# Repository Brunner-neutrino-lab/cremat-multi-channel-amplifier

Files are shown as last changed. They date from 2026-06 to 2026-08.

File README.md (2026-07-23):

# Multi-channel Cremat amplifier

A **12-channel** SiPM charge-sensitive preamplifier + Gaussian shaper board, derived
from the Brunner-lab **6-channel Cremat CSP & Shaper board**
([`cremat-x6-board`](reference/cremat-x6-board/)) with four deliberate changes:

1. **12 channels** (was 6).
2. **0805 passives wherever possible** (was a mix of larger imperial sizes).
3. **A Cremat CR-210 baseline restorer on every channel**, *optional* — populate the
   module **or** an 0805 `0R` jumper to bypass it.
4. **An on-board SiPM bias front-end on every channel**: a `BIAS_IN` feed through an
   *optional* RC-in-series-with-R **bias filter**, then a node shared by the **SiPM**
   (DC-coupled) and the **amplifier** (AC-coupled). The detector and the amplifier hang
   off the same biased node.

> This repository is the **design specification + build documentation** for the new
> board. It is structured to mirror the Brunner-lab **`ets-breakout`** project, which is
> included as the *reference for how to document and build*. The KiCad implementation is
> the next track (see [Status](#status)).

## What each channel does (new signal chain)

```
                          bias filter (optional, 0R-bypassable)
 BIAS_IN ───►  Rf1 ──┬── Rf2 ──►──┐
                     │            │   FRONT-END NODE
                    Cf            ├─────────────► SIPM   (DC-coupled: reverse-biases the detector)
                     │            │
                    GND           └─► Cc ─► CR-11X ─► CR-200-X ─► [CR-210] ─► buffer ─► OUTPUT
                                     (AC)   CSP        shaper     BLR(opt)   THS3491    (50 Ω
                                                       +P/Z trim  0R-byp.    DNP-def     coax)
```

- **`BIAS_IN` → bias filter → front-end node.** "RC in series with R": series `Rf1`,
  shunt `Cf` to ground, series `Rf2`. The whole filter is bypassable with 0R jumpers.
- **Front-end node → `SIPM` (DC-coupled).** The filtered bias voltage reverse-biases the
  detector directly.
- **Front-end node → `Cc` → amplifier (AC-coupled).** Only the SiPM's fast current pulse
  reaches the charge-sensitive preamp; the DC bias is blocked by `Cc`.
- **CR-11X → CR-200-X → CR-210 → buffer → output**, the classic Cremat chain. The CR-210
  baseline restorer is new and optional.

Full detail: [docs/hardware/channel.md](docs/hardware/channel.md).

## Documentation map

> **Looking for the actual orderable board? It is [`final-board/twelve-channel/`](final-board/twelve-channel/).**
> Reviewing it → [REVIEW.md](final-board/twelve-channel/REVIEW.md) · ordering it →
> [ORDERING.md](final-board/twelve-channel/ORDERING.md) · resuming work on it →
> [HANDOFF.md](final-board/twelve-channel/HANDOFF.md).

| Doc | Contents |
|-----|---|
| **[final-board/twelve-channel/REVIEW.md](final-board/twelve-channel/REVIEW.md)** | **Design-review pack** — verified state, the acceptance gate, and what needs human eyes before ordering |
| [final-board/twelve-channel/INTERFACE.md](final-board/twelve-channel/INTERFACE.md) | The final board: layout intent, connector map, stackup, per-channel cell |
| [final-board/twelve-channel/ORDERING.md](final-board/twelve-channel/ORDERING.md) | Buy sheet — JLCPCB (fab + SMT) + DigiKey (hand parts), quantities, upload steps |
| [final-board/twelve-channel/HANDOFF.md](final-board/twelve-channel/HANDOFF.md) | Resume on a new machine: toolchain, paths, regeneration commands, gotchas |
| [docs/agent-project/](docs/agent-project/) | **Parallel agent-developed build** — bottom-up (per-chip eval boards → single channel → 12-ch board), 12 tracks with briefs, conventions, session-log/report protocol. **Start at [docs/agent-project/README.md](docs/agent-project/README.md).** *(Historical: intermediate figures here — e.g. bias ≤ 60 V, board 235.1 × 264.1 mm — are superseded by the final board.)* |
| [docs/development-plan.md](docs/development-plan.md) | Earlier work-track breakdown (the rapid top-down build in `hardware/`); superseded by the agent-project for the final design |
| [docs/architecture.md](docs/architecture.md) | System/board block diagram, channel signal chain, design partitioning |
| [docs/modifications.md](docs/modifications.md) | **The four changes vs. `cremat-x6-board`, with rationale + the optional/DNP jumper scheme** |
| [docs/hardware/channel.md](docs/hardware/channel.md) | Per-channel circuit: bias front-end, AC/DC coupling, CSP/shaper/BLR/buffer, jumpers |
| [docs/hardware/circuit-design.md](docs/hardware/circuit-design.md) | **Front-end values for the Hamamatsu VUV4** — bias filter, coupling, polarity, CR-112 gain/range |
| [docs/hardware/board.md](docs/hardware/board.md) | 12-channel board: power distribution, connectors, layout intent |
| [docs/hardware/bom.md](docs/hardware/bom.md) | 0805 strategy, Cremat modules, optional-population (DNP) variants |
| [docs/hardware/pcb-design-rules.md](docs/hardware/pcb-design-rules.md) | Net classes, trace widths, HV creepage, guard rings |
| [docs/hardware/component-libraries.md](docs/hardware/component-libraries.md) | Symbols + footprints to provide (Cremat SIP-8, 0805 passives, jumpers) |
| [docs/fabrication/fabrication-guide.md](docs/fabrication/fabrication-guide.md) | Fab output generation, assembly, population variants |
| [docs/operation/user-guide.md](docs/operation/user-guide.md) | Power-up, biasing SiPMs, choosing populate/bypass options |
| [docs/session-report.md](docs/session-report.md) | Integration/manager handoff: tracks, decisions, what's done vs. open |

## References (git submodules)

| Path | Repo | Role |
|---|---|---|
| [reference/cremat-x6-board/](reference/cremat-x6-board/) | `Brunner-neutrino-lab/cremat-x6-board` | **What we're building** — the 6-channel CR-110/CR-200 eval board this design derives from |
| [reference/ets-breakout/](reference/ets-breakout/) | `Brunner-neutrino-lab/ets-breakout` | **How we build/document** — KiCad-from-source-of-truth pipeline + doc structure to imitate |
| [reference/cremat-CR-160-R7/](reference/cremat-CR-160-R7/) | `CrematInc/CR-160-R7` | **CR-210 pinout + integration** — Cremat's open-source CR-200/CR-210 eval board (the CR-210 bypass-jumper scheme) |
| [reference/cremat-CR-150-R5/](reference/cremat-CR-150-R5/) | `CrematInc/CR-150-R5` | **CR-11X reference** — Cremat's open-source CSP eval board (source of the CR-11X symbol) |

Clone with submodules:

```
git clone --recurse-submodules <this-repo>
# or, in an existing clone:
git submodule update --init --recursive
```

## Status

- **Specification + documentation: complete.** This repo fully specifies the modified
  12-channel board.
- **Development is divided into tracks** — see [docs/development-plan.md](docs/development-plan.md).
  **Phase 1 is built:** [hardware/](hardware/) has the `kicad-cli`-validated symbol library
  ([hardware/lib/cremat.kicad_sym](hardware/lib/cremat.kicad_sym)), the project + net classes,
  lib tables, the fielded BOM ([hardware/bom/](hardware/bom/)), the golden per-channel netlist
  ([hardware/integration-notes.md](hardware/integration-notes.md)), and the mechanical spec
  ([hardware/mechanical.md](hardware/mechanical.md)). **Track 5 (schematic) is done** — the
  12-channel hierarchical schematic is generated by [hardware/gen_sch.py](hardware/gen_sch.py)
  and is **ERC-clean (0 errors)** with a netlist that matches the spec node-by-node. **Layout
  + fab (Tracks 6–7)** remain — guide: [hardware/BUILD-IN-KICAD.md](hardware/BUILD-IN-KICAD.md).
- **CR-210 pinout + bypass-jumper integration: confirmed** against Cremat's open-source
  [CR-160-R7](reference/cremat-CR-160-R7/) board (pin 2 = GND vs the CR-200's P/Z).
- **Build decisions resolved** (D1–D6, see the plan): bias ≤ 70 V (100 V parts); all
  per-channel I/O is **MCX `CONMCX013`** (`BIAS_IN`, `SIPM`, `TEST`, `OUT_50` — **`BIAS_IN` is
  per-channel**, 4/channel → 48 MCX/board); modules **CR-112** + **CR-200-1µs** (+ CR-210),
  **socketed** on Samtec SS-108-TT-2 SIP-8 sockets (36/board), the modules plug in; rack-mounted,
  **one board per 1U Hammond RM1U1908VBK case, boards daisy-chained**; first build = Full.
- **Front-end designed for the Hamamatsu VUV4** (S13370, 45–55 V, ≈220 fC/V, Cdet≈1.28 nF):
  bias filter `Rf1=Rf2=10 kΩ`, `Cf=100 nF`, `Cc=0.22 µF`; cathode-on-node +45–55 V; CR-112
  ([docs/hardware/circuit-design.md](docs/hardware/circuit-design.md)).
- **Enclosure (D5):** **Hammond RM1U1908VBK** (1U, vented), **one board per case**; boards are
  **daisy-chained** (each board in its own 1U box, `J_DAISY` passes the raw rails box-to-box).
  Board outline **213.2 × 334.7 mm**; it mounts on standoffs off the bottom cover and passes
  **through a ~340 × 7 mm milled slot** in each front/rear panel (slot-through, protruding ~5 mm;
  the MCX faces sit ~8.6 mm proud). Usable interior height 40.09 mm; tall parts must clear it.
  Inputs (`BIAS_IN`+`SIPM`) on one long edge, outputs (`OUT_50`) on the other (24 MCX per long edge).
- **Open items**: final jack/outline placement (Track 4), and bench-verify (CR-112 output
  sign, warm/cold OV offset, single-p.e. range, P/Z trim). Power terminals are resolved —
  two 3-pos 5.08 mm Phoenix screw terminals, `J_PWR` (supply in) + `J_DAISY` (raw rails out).

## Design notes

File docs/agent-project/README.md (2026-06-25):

# Agent-developed build — start here

This directory orchestrates the **parallel, agent-developed** rebuild of the amplifier
(bottom-up: per-chip eval boards → single channel → 12-channel board). Run sessions in
danger/bypass mode.

## Read order
1. [00-CHARTER.md](00-CHARTER.md) — phases, the 12 tracks, dependency graph, gating, locked decisions.
2. [01-CONVENTIONS.md](01-CONVENTIONS.md) — directory layout, log/report protocol, interface contracts, toolchain, **SPICE rules (use Cremat's official models)**, real-parts gate, sourcing rules, success-criteria philosophy.
3. Your **brief** (below). 4. The reports/`INTERFACE.md` your brief says to consume.

## How to assign a session
Give the new session this (fill in the track):

> You are **track `<ID>`** of the agent-developed Cremat amplifier project. Read
> `docs/agent-project/00-CHARTER.md`, `docs/agent-project/01-CONVENTIONS.md`, and your brief
> `docs/agent-project/briefs/<brief>.md`. Work only in your track subdir, keep
> `SESSION_LOG.md` (ground truth) + `SESSION_REPORT.md` (summary) current from the templates,
> update your row in `docs/agent-project/02-TRACKS.md`, define your success/failure criteria
> first, then execute autonomously. Honor the gates in the charter.

| Track | Brief | Subdir |
|---|---|---|
| A1 csp-design / A2 csp-sim / A3 csp-bom | [briefs/A-csp-cr112.md](briefs/A-csp-cr112.md) | `chips-board/csp-cr112/{design,sim,models-bom}/` |
| A4/A5/A6 shaper {design,sim,bom} | [briefs/A-shaper-cr200-cr210.md](briefs/A-shaper-cr200-cr210.md) | `chips-board/shaper-cr200-cr210/...` |
| B1/B2/B3 single-channel {design,sim,bom} | [briefs/B-single-channel.md](briefs/B-single-channel.md) | `integration/single-channel/...` |
| C1/C2/C3 twelve-channel {design,bom,sim} | [briefs/C-twelve-channel.md](briefs/C-twelve-channel.md) | `final-board/twelve-channel/...` |

Phase A (6 tracks) can all start now. Phase B gates on both Phase-A sub-components COMPLETE;
Phase C gates on single-channel COMPLETE. The **Coordinator** owns
[02-TRACKS.md](02-TRACKS.md) and marks COMPLETE.

## Prior art (read-only)
`reference/` (incl. Cremat's `cremat-CR-150-R5`, `cremat-CR-160-R7` eval boards), and the
earlier rapid build in `hardware/` + `docs/` — reuse the toolchain/scripts, but this
bottom-up build is the source of truth for the final design.

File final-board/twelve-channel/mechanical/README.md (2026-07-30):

# Box mounting — two boards stacked in a 2U rack case

Two 12-channel boards stacked on standoffs in **one Hammond RM2U1908VBK** 2U vented case
(DigiKey HM1166-ND). The other 3 assembled boards are spares (unboxed). Drawings are the
`*.svg` files here (regenerate with `python gen_drawings.py <png_out_dir>`).

## Box + board

| | mm |
|---|---|
| Box interior (Hammond drawing) | **84.53 H × 415.30 W × 196.85 D** |
| Board | 213.3 (depth, connectors) × 334.8 (width) × 1.6 |
| Board mounting holes | 4× M3 (3.2 mm) at board-x {8.0, 205.2}, board-y {5.0, 329.7} |

## Horizontal placement (drawings 1, 5)

- **Width:** board 334.8 mm centered → **40.25 mm clear each side.**
- **Depth:** board is 16.45 mm **deeper** than the box → protrudes **8.2 mm past each panel**;
  the 24+24 MCX sit proud through the front/rear slots.
- **Standoff holes (bottom cover):** X = **45.25 / 369.95** mm (from the left interior wall),
  Y ≈ **0 / 196.85** mm. ⚠ The hole rectangle (197.2 mm) is 0.35 mm wider than the 196.85 mm
  interior, so the holes land **right on the front/rear panel lines** — the front/rear panels
  need a small corner-relief cutout at X = 45.25 / 369.95 for the standoff columns (they're
  outside the connector-slot span X ≈ 69–356, so the relief is clean).

## Vertical stack (drawings 2, 3, 4) — target 1″ board-to-board

| From → to | height |
|---|---|
| bottom cover → board 1 | **12.7 mm (½″)** standoff |
| board 1 → board 2 | **25.4 mm (1″)** standoff — the board-to-board spec |
| board 2 → top cover | **43.2 mm** air |

Board planes (connector-slot centers): **Z = 13.5 mm** (board 1), **Z = 40.5 mm** (board 2).
Sum: 12.7 + 1.6 + 25.4 + 1.6 + 43.2 = 84.53 ✓.

A standing Cremat module is **~26.5 mm** (socket 4.2 + body ~22.3) — **1.1 mm taller than the
25.4 mm gap**, so **board 1's modules bend** to fit the inter-board gap (as on Cremat's own eval
boards); board 2's modules stand freely in the 43 mm top clearance.

*Standoff note:* the recommended in-stock parts are metric (12 mm / 25 mm), 0.7 / 0.4 mm short of
½″ / 1″. That makes board-to-board 25.0 mm (~0.98″); the 0.4 mm is absorbed by the top air. Source
true 25.4 / 12.7 mm M3 M-F standoffs if exact-inch is required.

## Panels (drawings 3, 4) — machine into the removable front/rear plates

- **2 connector slots** each, ~8 mm tall, X 69.2 → 356.2, at Z = 13.5 (board 1) and Z = 40.5 (board 2).
- **2 standoff-relief cutouts** each, ~8 mm wide, at X = 45.25 / 369.95, from the bottom up to Z ≈ 42.

## Standoff hardware (per box, DigiKey — see `../models-bom/digikey-hand-bom.csv`)

All M3. Both standoffs are **male-female, male-up** (an F-F bottom standoff won't mate with B).

| Role | MPN | DK PN | length |
|---|---|---|---|
| A — bottom cover → board 1 | Würth 971120321 | 732-10406-ND | 12 mm + 6 mm stud |
| B — board 1 → board 2 | Würth 971250321 | 732-971250321-ND | 25 mm + 6 mm stud |
| screw (into A, from under cover) | Keystone 29311 | 36-29311-ND | M3×6 mm pan |
| nut (top of B, fixes board 2) | Keystone 4708 | 36-4708-ND | M3 |

## Assembly (per the described order of operations)

1. Remove front, rear, and top panels. Machine the front/rear panel slots + corner reliefs.
2. Drill the 4 standoff holes in the bottom cover (match the PCB: X 45.25/369.95, Y ~0/196.85).
3. Screw the 4× standoff **A** (12 mm) to the bottom cover from below.
4. Slide **board 1** in through the front; drop onto standoffs A (male studs through the holes).
5. Thread the 4× standoff **B** (25 mm) onto A through board 1 → clamps board 1.
6. Slide **board 2** in; drop onto standoffs B; **fix a nut** on each top stud.
7. Refit the front/rear panels (over the protruding board edges / connectors) and the top.

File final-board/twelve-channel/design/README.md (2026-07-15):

# twelve-channel — design (schematic + PCB)

12-channel SiPM CSP + shaper + BLR + buffer board, built from the reworked single channel
(`../../../integration/single-channel/design/`) as the single source of truth.

- **Schematic** = KiCad **hierarchical**: the single channel (minus board power entry)
  instantiated 12× as `channel.kicad_sch`, plus a root `twelve-channel.kicad_sch` with the 12
  sheet instances + one common power section (power in + board-to-board daisy + up-rated
  reverse-polarity/PTC block + 470 µF bulk). Per-channel nets auto-scope to `/chNN/<net>`.
- **PCB** = **tile-and-replicate**: the routed single-channel channel row is cloned 12× (offset
  25 mm in Y, refs re-mapped via role, nets re-mapped `/X`→`/chNN/X`); board-wide plane pours
  carry the rails so the router does no per-channel work; only the common section is routed.

## Pipeline (run in order; KiCad 10 bundled Python)

```
PY="C:/Program Files/KiCad/10.0/bin/python.exe"
CLI="C:/Program Files/KiCad/10.0/bin/kicad-cli.exe"

# --- schematic ---
"$PY" gen_sch.py                       # -> channel.kicad_sch, twelve-channel.kicad_sch, .kicad_pro
"$CLI" sch erc twelve-channel.kicad_sch
"$CLI" sch export netlist --format kicadsexpr -o twelve-channel.net twelve-channel.kicad_sch

# --- PCB (needs twelve-channel.net from the step above) ---
"$PY" gen_pcb.py                       # tile x12 + common section + planes + outline (+ .kicad_dru)
"$PY" fill_zones.py                    # fill the 4 plane zones (separate pass; in-memory fill segfaults)
"$PY" polish_silk.py                   # move dense refdes/fields F.Silkscreen -> F.Fab
"$CLI" pcb drc --schematic-parity twelve-channel.kicad_pcb    # gate: 0 / 0 / 0
```

Note: `gen_pcb.py` resets silk and adds visible common-part fields, so **`polish_silk.py` must
run after every `gen_pcb.py`**. The `twelve-channel.net` netlist is the authoritative source
for the PCB's per-pad nets, footprint values, and BOM fields (regenerate it after any schematic
change before re-running `gen_pcb.py`).

## Result

213.2 × 334.7 mm, 4-layer (widened 138 → 180 → 213.2 mm to span the Hammond RM1U1908VBK 1U case —
one board per case, slot-through the front/rear panels; the output/bias MCX row was shifted to the
far edge with F.Cu trace extensions). 468 footprints (464 refdes'd parts + 4 M3), 4 plane
zones. (The BOM lists 500 line-item parts = the 464 placed + the 36 SIP-8 sockets, which
share the module sites' PinSocket_1x08 footprints.)
**DRC 0 violations / 0 unconnected / 0 schematic-parity.** Render: `twelve-channel-3d.png`.

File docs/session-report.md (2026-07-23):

# Session report — Multi-channel Cremat amplifier (integration track)

> **Superseded 2026-07-11 (historical setup-phase handoff).** The board is now BUILT and
> order-ready: 213.2 × 334.7 mm, 4-layer, one per Hammond RM1U1908VBK 1U case (slot-through,
> daisy-chained), THS3491 output buffer (DNP-by-default), socketed Cremat modules (Samtec
> SS-108-TT-2). The mechanical/part figures below (e.g. 225 × 235 mm, two boards side-by-side,
> EL5167) reflect the initial plan, not the final board. Current truth: `final-board/twelve-channel/`
> (INTERFACE.md, HANDOFF.md, ORDERING.md, SESSION_LOG sessions 12–15).

Handoff from the **organizing / integrating / managing** track. This session set up the
repository, integrated the two reference projects as submodules, and authored the full
design-specification documentation set for the modified 12-channel board. It did **not**
implement the KiCad project — that is the hardware track's job, and this report is its
brief.

---

## 1. What this session produced

- **Four git submodules under `reference/`:**
  - `cremat-x6-board` (`Brunner-neutrino-lab/cremat-x6-board`) — *what we build*: the
    6-channel CR-110/CR-200 eval board this design derives from.
  - `ets-breakout` (`Brunner-neutrino-lab/ets-breakout`) — *how we build/document*: the
    single-source-of-truth KiCad pipeline + the docs structure imitated here.
  - `cremat-CR-160-R7` (`CrematInc/CR-160-R7`) — *CR-210 reference*: Cremat's open-source
    CR-200/CR-210 eval board; the authority for the CR-210 pinout + bypass-jumper scheme.
  - `cremat-CR-150-R5` (`CrematInc/CR-150-R5`) — *CR-11X reference*: Cremat's open-source
    CSP eval board (origin of the CR-11X symbol).
- **A track breakdown** ([development-plan.md](development-plan.md)): one foundation track
  for parts/models/BOM, parallel tracks for circuit / integration / mechanical, then serial
  schematic → layout → fab tracks, with a dependency graph and the decision list.
- **A complete documentation set** (`README.md`, `CLAUDE.md`, `docs/…`) specifying the
  modified board, with the change list, per-channel circuit, board plan, BOM/DNP logic,
  PCB rules, library plan, fabrication, and operation.
- **Repo hygiene:** `.gitignore` for KiCad/Python/fab cruft.

The documentation is structured so a hardware track (or a future Claude session) can
implement the KiCad project directly from `docs/modifications.md` + the reference channel
sheet.

---

## 2. The design in one paragraph

Take the reference per-channel chain
(`coax → Cc → CR-113 → CR-200-X → buffer → 49.9R → coax`), and: (1) replicate it **12×**;
(2) move all passives to **0805**; (3) insert an **optional CR-210** baseline restorer
between shaper and buffer (0R-bypassable); (4) add an **on-board SiPM bias front-end** —
`BIAS_IN` through an optional RC-in-series-with-R filter to a node that feeds the **SiPM
DC-coupled** and the **amplifier AC-coupled** (via `Cc`). Both detector and amplifier hang
off the one biased node. Full detail in [modifications.md](modifications.md) and
[hardware/channel.md](hardware/channel.md).

---

## 3. Key decisions (with rationale)

- **Documentation-first, mirroring `ets-breakout`.** The user named `ets-breakout` as the
  "how to build" reference; it is fundamentally a markdown doc set + a generated KiCad
  project with a DRC gate. This repo reproduces the doc set now and leaves a clean slot
  (`hardware/`) for the generated project.
- **"Optional" = populate-or-bypass via 0R, resolved by DNP.** No switches/relays. The
  reference board already uses solder/2-pin/3-pin jumpers, so this is idiomatic. The
  mutual-exclusivity of a block and its 0R is the board's one assembly invariant.
- **0805 applies to passives only.** Cremat modules are SIP-8 through-hole; op-amps and
  jacks are their own packages. The docs say so explicitly to avoid an impossible BOM.
- **Bias front-end is the real design work.** Drawn terminal-agnostic; the AC/DC split is
  the standard SiPM readout. The new per-channel HV bias nets drove the addition of an `hv_bias` net
  class with voltage-derived creepage.
- **Single board, not a multi-board system.** Unlike the reference IV-mux systems, this is
  one 12-channel PCB with no controller/firmware.

---

## 4. Status — done vs. open

**Done (this track):** submodules wired; complete spec/docs; repo hygiene.

**Built (Tracks 1, 3, 4 — real, `kicad-cli`-validated artifacts under `hardware/`):**
- `lib/cremat.kicad_sym` (CR-11X/CR-112, CR-200, CR-210, EL5167) — validated with
  `kicad-cli sym upgrade` on KiCad 10. `sym-lib-table`/`fp-lib-table`, the
  `.kicad_pro` with net classes (Default/power/hv_bias/signal + pattern assignment),
  `bom/` (fielded Full-variant BOM + CSV), `integration-notes.md` (golden netlist),
  `mechanical.md`. See [hardware/BUILD-IN-KICAD.md](../hardware/BUILD-IN-KICAD.md).

**Track 5 — schematic: DONE headless (ERC 0 errors).** The earlier "GUI boundary" call was
wrong (corrected per [KICAD_WITH_CLAUDE_CODE.md](KICAD_WITH_CLAUDE_CODE.md)): a generator
[hardware/gen_sch.py](../hardware/gen_sch.py) writes `channel.kicad_sch` + the 12× root by
placing symbols at rotation 0 and dropping net-labels (local) / global-labels (rails) at
exact pin coordinates. `kicad-cli sch erc` → **0 errors** (4 warnings = MCX + screw-terminal
footprint links, expected); exported netlist matches integration-notes.md node-by-node
(217 unique refs, 12 independent `/chN/FE`, global `+VDC/-VDC/GND`).

**Open — Tracks 6/7 (KiCad; toolchain ready):**
1. **MCX footprint** `MCX_CONMCX013_EdgeMount` (datasheet-verified) — the one to-create part.
2. **Layout** (placement via `pcbnew` Python API or file-authoring; dense routing in GUI;
   DRC 0) and **fab** (gerbers/drill/pos + BOM). Guide: `hardware/BUILD-IN-KICAD.md`.

**Resolved this session:**
- ✅ **CR-210 pin map.** Confirmed from `reference/cremat-CR-160-R7` (`CR-160-R7-cache.lib`
  + netlist): `1=input, 2=GND, 3=GND, 4=-Vs, 5=+Vs, 6=GND, 7=GND, 8=output` — identical to
  the CR-200 except pin 2 (P/Z → GND). The CR-160-R7 also confirms the **optional**
  integration: a jumper (`JU1`) across the module's input/output nodes — exactly our
  `JP_BLR` 0R scheme.

**Resolved — Track 2 front-end design** (target = Hamamatsu VUV4 S13370, 6 mm/75 µm;
45–55 V reverse, ≈ 220 fC/V OV, `Cdet` ≈ 1.28 nF — see
[hardware/circuit-design.md](hardware/circuit-design.md)):
- ✅ **Bias filter values:** `Rf1=Rf2=10 kΩ`, `Cf=100 nF/100 V` (`fc≈159 Hz`; cold-only
  boards may raise `Rf` to 100 kΩ–1 MΩ). `Cc=0.22 µF/100 V` (≫ `Cdet` → ~99 % charge transfer).
- ✅ **Polarity:** cathode on the front-end node, **+45…55 V**; anode → GND; positive bias
  supply. CR-112 (13 mV/pC) confirmed appropriate for the VUV4 charge.

**Open — bench-verify (Track 2 checklist, after first boards):** CR-112 output-step sign;
warm-vs-cold OV offset from the 20 kΩ drop; single-p.e. amplitude / CR-112-vs-CR-113 range;
pole-zero trim.

**Resolved — product decisions (D1–D6).** Summarised here; the **decision table in
[development-plan.md](development-plan.md#decisions--resolved-2026-06-24) is authoritative** if
the two ever disagree:

- **D1 bias:** **≤ 70 V**, HV parts (`Cc`,`Cf`) rated **100 V** → `hv_bias` **0.6 mm** clearance /
  0.4 mm track, as fabbed. *(An earlier ≤ 60 V figure from 2026-06-29 is superseded; both are
  covered by the 0.6 mm clearance actually built, so no copper is affected. `docs/agent-project/`
  still shows the 60 V intermediate state and is explicitly historical.)*
- **D2/D3 connectors:** all per-channel I/O — including `BIAS_IN` — is MCX `CONMCX013`;
  **`BIAS_IN` is per-channel**, not a shared rail (architecture correction).
- **D4 modules:** CR-112 CSP + CR-200-1µs shaper (+ CR-210 BLR), all socketed.
- **D5 enclosure:** **Hammond RM1U1908VBK 1U vented case, ONE board per case**, boxes
  daisy-chained via `J_DAISY`. Board **213.2 × 334.7 mm**, passing through a ~340 × 7 mm slot
  milled in each front/rear panel (slot-through); tall parts **< ~40 mm**.
- **D6 first build:** **Full** variant (bias filter fitted + CR-210 fitted).

---

## 5. Notes for whoever picks this up

- `reference/` holds **submodules** — never edit inside them or commit into them. Do the
  new design at the top level / under `hardware/`.
- The reference channel sheet
  (`reference/cremat-x6-board/channel.kicad_sch`) is large (~5k lines of s-expr); the
  components and values were extracted into [hardware/channel.md](hardware/channel.md) /
  [hardware/bom.md](hardware/bom.md) so you don't have to re-parse it.
- `CLAUDE.md` carries the iron rules; keep the DNP tables in `hardware/bom.md` as the
  single source of truth for what's populated in each variant.

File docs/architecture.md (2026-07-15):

# System Architecture

## Purpose

The Multi-channel Cremat Amplifier is a **12-channel analog front-end** for Silicon
Photomultipliers (SiPMs) and similar charge-producing detectors. Each channel:

1. **Biases** its detector from its own per-channel `BIAS_IN` jack through an optional
   filter, and
2. **Amplifies and shapes** the detector's charge pulses with the Cremat module chain
   (charge-sensitive preamp → Gaussian shaper → optional baseline restorer → buffer),
   presenting a 50 Ω-driven pulse at a per-channel coax output.

It is a remake of the Brunner-lab **6-channel Cremat CSP & Shaper board**
(`reference/cremat-x6-board/`, *"6 Channel Cremat CSP & Shaper Board"*, McGill Physics /
Brunner Neutrino Lab, 2023) with the four modifications listed in
[modifications.md](modifications.md). Unlike the reference board — which took an already
externally-biased detector signal in on coax — this board **biases the detector itself**.

The **target detector is the Hamamatsu VUV4 MPPC** (S13370, 6 mm / 75 µm; 45–55 V reverse
bias, ≈ 220 fC per V overvoltage, `Cdet` ≈ 1.28 nF). Per-channel component values are
designed for it in [circuit-design.md](hardware/circuit-design.md).

---

## Board Block Diagram

```
        +Vs  -Vs  GND
         │    │    │
   ┌─────┴────┴────┴───────────────────────────────────────────────────────────┐
   │  Power entry + bulk decoupling  (±Vs, GND distributed to all modules)       │
   │                                                                             │
   │   ┌──────────────── Channel 1 ─────────────────┐   BIAS_IN1 ◄─(bias supply) │
   │   │ bias filter → node → SiPM (DC) / amp (AC)   │   SIPM1   ──►(to detector) │
   │   │ CR-11X → CR-200-1µs → [CR-210] → buffer     │   OUT1    ──►(to DAQ/coax) │
   │   └─────────────────────────────────────────────┘                           │
   │   ┌──────────────── Channel 2 ─────────────────┐   BIAS_IN2 / SIPM2 / OUT2   │
   │   │  … identical …                              │                            │
   │   └─────────────────────────────────────────────┘                           │
   │            ⋮  (12 identical channels)             BIAS_IN12 / SIPM12 / OUT12 │
   └───────────────────────────────────────────────────────────────────────────┘
        Every channel has its own 4 MCX jacks: BIAS_IN, SIPM, TEST, OUT_50 (48 MCX total).
```

All 12 channels are **electrically identical** and instantiated from one hierarchical
sheet, exactly as the reference board instantiates `channel.kicad_sch` six times. The
board adds, per channel, the bias front-end (with its own `BIAS_IN` jack) and the CR-210
stage. **`BIAS_IN` is per-channel** — there is no shared on-board bias rail; the bias
supply is fanned to the 12 `BIAS_IN` jacks externally, or each channel is biased on its own.

---

## Per-channel Signal Chain

```
                          bias filter (optional, 0R-bypassable)
 BIAS_IN ───►  Rf1 ──┬── Rf2 ──►──┐
                     │            │  FRONT-END NODE  (node "FE")
                    Cf            ├──────────────────► SIPM connector
                     │            │                    (DC-coupled: reverse-biases detector)
                    GND           │
                                  └─► Cc ─► [ CR-11X ] ─► [ CR-200-X ] ─► [ CR-210 ] ─► [ buffer ] ─► OUT
                                     AC      charge-       Gaussian        baseline      THS3491      50 Ω
                                     coupling sensitive     shaper          restorer      CFA buf      coax
                                              preamp        (+P/Z trim)     (optional)    (DNP by def)
```

| Stage | Part (reference board) | Function | New? |
|---|---|---|---|
| Bias filter | `Rf1`, `Cf`, `Rf2` (0805) | Low-pass + isolate the SiPM bias from supply noise | **New** |
| Front-end node | — | Shared by SiPM (DC) and amplifier (AC) | **New** |
| AC coupling | `Cc` (HV cap, e.g. 0.22 µF 100 V) | Block DC bias, pass the current pulse to the preamp | (reference input cap) |
| Charge-sensitive preamp | Cremat **CR-112** (CR-113 on ref.) | Integrate detector charge → voltage step | existing |
| Shaping amplifier | Cremat **CR-200-1µs** | Gaussian pulse shaping (1 µs); pole-zero trimmed | existing |
| Baseline restorer | Cremat **CR-210** | Hold baseline at ground at high rate | **New, optional** |
| Output buffer | **TI THS3491** CFA + `49.9R` series | Drive 50 Ω coax — **DNP by default**; a 0R jumper bypasses it so the shaper/BLR drives the 49.9 Ω back-termination directly | existing (now **opt., DNP**) |

See [hardware/channel.md](hardware/channel.md) for component-level detail and the bypass
jumper scheme.

---

## Design Partitioning

### Why one repeated channel cell?
12 channels of identical analog electronics is exactly the case KiCad's hierarchical
sheets handle well. One reviewed, DRC-clean channel cell instantiated 12× guarantees the
channels match and keeps the schematic reviewable — the same pattern the reference board
uses for 6 channels and that `ets-breakout` uses for 24.

### Why an on-board bias front-end?
The reference board amplified an already-biased signal arriving on coax. Folding the bias
network onto the board means the **detector connects with one cable** (the on-board
bias-tee both biases the SiPM and reads it out on the `SIPM` jack), removes an external
bias-tee, and lets the bias filter sit right at the detector node where it does the most
good. The penalty is that the board now carries HV (the 12 per-channel `BIAS_IN` nets,
≤ 70 V) — handled by net-class spacing and 100 V-rated parts (see
[pcb-design-rules.md](hardware/pcb-design-rules.md)).

### Why everything optional is a jumper, not a switch
Populate-or-bypass via 0R / solder jumpers (resolved by DNP at assembly) is zero-cost,
zero-failure, and needs no control logic. Each build is a fixed configuration; there is no
runtime switching. This matches the reference board's existing use of `SolderJumper`,
`Jumper_2_Open`, and `Jumper_3_Open` parts.

---

## Power and Bias Domains

| Domain | Nets | Source | Notes |
|---|---|---|---|
| Analog supply | `+VDC` / `-VDC` (±Vs), `GND` | External dual rail (Cremat-style, typ. ±12 V) | Per-module + bulk decoupling; **shared** across channels |
| Detector bias | `BIAS_IN<n>` (HV, ≤ 70 V) | External bias supply, fanned out | **Per-channel** jack → per-channel filter → SiPM. No shared on-board rail. |

The analog supply and the detector bias are **independent**. `GND` is the common
reference for both. The 12 `BIAS_IN<n>` nets are the only HV nets (≤ 70 V; parts rated
100 V) and each is kept on its own routing with widened creepage near its filter.

---

## What this board does *not* do

- **No multiplexing / no switching / no microcontroller.** Every channel is always live;
  there is no firmware (contrast the `ets-breakout`/IV-pulse-mux system, which is a
  relay mux with an Arduino). This is a parallel analog amplifier array.
- **No *on-board* per-channel bias adjust.** Each channel has its own `BIAS_IN` jack, so
  per-channel bias *is* possible by driving each jack separately — but the board itself
  does no on-board trimming/regulation of the bias (the optional filter only low-passes it).

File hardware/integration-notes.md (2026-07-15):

# Integration Notes — golden per-channel netlist (Track 3 deliverable)

The authoritative per-channel connectivity for schematic capture (Track 5). Pinouts are
confirmed from the Cremat open-source boards; values from
[../docs/hardware/circuit-design.md](../docs/hardware/circuit-design.md).

## Hierarchy

```
multi-channel-cremat-amplifier.kicad_sch   (root)
  ├─ power: J_PWR screw terminal → +VDC / -VDC / GND distributed to all sheets
  └─ channel.kicad_sch  ×12   (each instance carries its own 4 MCX jacks)
```

The channel sheet has **three hierarchical pins only: `+VDC`, `-VDC`, `GND`** (the shared
analog supply). Everything else — `BIAS_IN`, `SIPM`, `OUT`, and all internal nodes — is
**local to the sheet**, so each of the 12 instances gets its own independent copy. `BIAS_IN`
is therefore per-channel (its own `J_BIAS` MCX on the sheet), not a shared rail.

## Confirmed module pinouts (SIP-8)

| Pin | CR-112 (`U_CSP`) | CR-200-1µs (`U_SHAPER`) | CR-210 (`U_BLR`) |
|---|---|---|---|
| 1 | input | input | input |
| 2 | GND | **P/Z** | **GND** |
| 3 | NC | GND | GND |
| 4 | GND | -Vs | -Vs |
| 5 | -Vs | +Vs | +Vs |
| 6 | +Vs | GND | GND |
| 7 | GND | GND | GND |
| 8 | output | output | output |

(CR-200/CR-210 from `reference/cremat-CR-160-R7`; CR-11X from `reference/cremat-CR-150-R5`.
CR-210 = CR-200 except pin 2: P/Z → GND.) Buffer `U_BUF` (**TI THS3491**, 8-pin
HSOIC/DDA PowerPAD): as WIRED IN THIS DESIGN (`gen_sch.py`) — 1=GND (REF), 2=VIN− (feedback),
3=VIN+ (input), 4=−VS, 5=NC, 6=VOUT, 7=+VS, 8=+VS (tied to pin 7 → PD held high = enabled).
The **thermal pad (EP, pin 9) ties to −VS** (the DDA PowerPAD is internally connected to −VS),
**not** to GND.

## Per-channel net → pin map

Local nets (per instance): `BIAS_IN, N_filt, FE, CSP_IN, CSP_OUT, SH_OUT, PZ, BLR_OUT,
BUF_OUT, OUT`. Shared (hierarchical): `+VDC, -VDC, GND`.

| Net | Connects (pins) |
|---|---|
| `BIAS_IN` | `J_BIAS`.1 (center) · `Rf1`.1 · `JP_Rf1`.1 |
| `N_filt` | `Rf1`.2 · `Cf`.1 · `Rf2`.1 · `JP_Rf1`.2 · `JP_Rf2`.1 |
| `FE` (front-end node) | `Rf2`.2 · `JP_Rf2`.2 · `J_SIPM`.1 (center) · `Cc`.1 |
| `CSP_IN` | `Cc`.2 · `U_CSP`.1 |
| `CSP_OUT` | `U_CSP`.8 · `U_SHAPER`.1 |
| `PZ` | `U_SHAPER`.2 · `RV_PZ` (pole-zero network, see note) |
| `SH_OUT` | `U_SHAPER`.8 · `U_BLR`.1 · `JP_BLR`.1 |
| `BLR_OUT` | `U_BLR`.8 · `JP_BLR`.2 · `JP_BUF`.1 · buffer input network (→ `U_BUF`.3 = VIN+ via Rin) |
| `BUF_OUT` | `U_BUF`.6 (VOUT) · `R_OUT`.1 · `JP_BUF`.2 · buffer feedback network (→ `U_BUF`.2 = VIN−) |
| `OUT` | `R_OUT`.2 · `J_OUT`.1 (center, the 50 Ω `OUT_50` jack) |
| `+VDC` | `U_CSP`.6 · `U_SHAPER`.5 · `U_BLR`.5 · `U_BUF`.7 (+VS) · `U_BUF`.8 (+VS, tied to pin 7) · decoupling |
| `-VDC` | `U_CSP`.5 · `U_SHAPER`.4 · `U_BLR`.4 · `U_BUF`.4 (−VS) · `U_BUF`.9 (thermal pad / EP → −VS) · decoupling |
| `GND` | `U_CSP`.{2,4,7} · `U_SHAPER`.{3,6,7} · `U_BLR`.{2,3,6,7} · `U_BUF`.1 (REF → GND) · `U_BUF`.5 (NC) · `Cf`.2 · `J_*`.2 (shields) · decoupling returns |

> Each channel has a **4th MCX, `J_TEST`** (charge-injection input), in addition to
> `J_BIAS`, `J_SIPM`, `J_OUT` (= the 50 Ω `OUT_50`) above — 4 jacks/channel, 48/board. It
> couples into the CSP input (`CSP_IN`) through a small test capacitor per the reference
> channel; its exact network is finalized at schematic capture.

## The three bypass jumpers (populate-XOR)

- **Bias filter:** `JP_Rf1` parallels `Rf1` (`BIAS_IN`↔`N_filt`); `JP_Rf2` parallels `Rf2`
  (`N_filt`↔`FE`). Fitted filter ⇒ `Rf1/Rf2/Cf` populated, `JP_Rf*` DNP. Bypassed ⇒ `JP_Rf*`
  = 0 Ω, `Rf1/Rf2/Cf` DNP ⇒ `BIAS_IN`=`FE` (straight through).
- **CR-210:** `JP_BLR` parallels the module (`SH_OUT`↔`BLR_OUT`). Fitted ⇒ `U_BLR`
  populated, `JP_BLR` DNP. Bypassed ⇒ `JP_BLR` = 0 Ω, `U_BLR` DNP ⇒ `SH_OUT`=`BLR_OUT`.
- **THS3491 buffer:** `JP_BUF` parallels the buffer (`BLR_OUT`↔`BUF_OUT`). **Default build
  is bypassed** ⇒ `JP_BUF` = 0 Ω, `U_BUF` DNP ⇒ `BLR_OUT`=`BUF_OUT` (shaper/BLR drives
  `R_OUT` directly). Buffered ⇒ `U_BUF` populated, `JP_BUF` DNP.

This mirrors the CR-160-R7 `JU1`-across-the-module pattern (now an 0805 0R).

## Notes for capture (carry from the reference channel)

- **Pole-zero network** (`U_SHAPER`.2, `RV_PZ` 200 kΩ 25-turn) follows
  `reference/cremat-x6-board/channel.kicad_sch` — reuse that sub-circuit, resizing passives
  to 0805.
- **Output buffer** is now a **TI THS3491** CFA (8-pin HSOIC/PowerPAD), **DNP by default**
  with a `JP_BUF` 0R bypass so the shaper/BLR drives `R_OUT` (49.9 Ω) directly. When fitted,
  set gain with its own `Rf`/`Rg` per the THS3491 datasheet — **there are no gain/offset
  trimpots** (the EL5163/LM7321-era `RV_GAIN`/`RV_OFS` are gone). Give it its own ±VS
  decoupling. Per the schematic: pin 8 ties to +VS (holds PD high = enabled), pin 1 (REF)
  ties to GND, and the thermal pad (EP, pin 9) ties to −VS.
- **Decoupling:** 0.1 µF / 1 µF / 10 µF per `±Vs` rail at each module, per the reference.
- **Capture technique:** internal nets can be wired by **local labels** (the names above);
  only `+VDC/-VDC/GND` need hierarchical pins. This keeps the 12× instantiation clean.

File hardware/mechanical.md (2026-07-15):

# Mechanical Spec (Track 4 deliverable)

Outline, placement, and mounting for PCB layout (Track 6). Decisions D2/D3/D5 from
[../docs/development-plan.md](../docs/development-plan.md); intent in
[../docs/hardware/board.md](../docs/hardware/board.md).

## Enclosure

- **Hammond RM1U1908VBK** — 1U, **vented**, 19" rack; **one 12-channel board per case.**
  Usable interior **196.85 mm (D) × 40.09 mm (H) × 415.30 mm (W)** (1U outer nominal is
  44.45 mm; usable interior height is 40.09 mm).
- The board is **enclosed** (not an open tray): it mounts on standoffs off the case
  **bottom cover** and passes **slot-through** the front and rear panels (see Panel
  mounting below).
- **Multiple boards are daisy-chained**, each in its own 1U box — `J_DAISY` passes the raw
  supply rails box-to-box. Never two boards stacked or side-by-side in one case.

## Per-board outline

- **213.2 mm × 334.7 mm**, 4-layer (F.Cu / In1 = GND plane / In2 = −VDC plane /
  B.Cu = +VDC pour).
- The 334.7 mm **long edges** run parallel to the front/rear panels and carry the MCX. The
  board is deeper (213.2 mm) than the case interior depth (196.85 mm), so it **protrudes
  ~5 mm through a milled slot in each panel** and the MCX faces sit **~8.6 mm proud** for
  snap-on cables (see Panel mounting).
- **Component height < ~40 mm** above the board (1U usable interior 40.09 mm − standoff).
  Tallest parts: the **socketed** vertical Cremat SIP-8 modules, the THT trimpots, and the
  electrolytics. Use low-profile parts where there's a choice. Board-edge MCX with
  **horizontal** cable exit (no vertical jacks).

## Panel mounting (slot-through)

- The board passes **through a ~340 mm × 7 mm milled slot** in each front and rear panel
  (the 334.7 mm long edge in a ~340 mm slot). It **protrudes ~5 mm** beyond each panel and
  the edge-mount MCX faces sit **~8.6 mm proud** so snap-on cables mate in the open —
  **not** bulkhead-flush, **not** an open tray.
- Vertical support is the standoffs off the bottom cover; the panel slots locate the board
  fore/aft.

## Jack placement (48 × MCX `CONMCX013`)

**4 MCX per channel** (`BIAS`, `SIPM`, `TEST`, `OUT_50`) = 48 total, **24 per long
(~334.7 mm) edge**, following signal flow:

```
   ┌──────────────── INPUT edge (~334.7 mm) ────────────────┐
   │  BIAS1 SIPM1  BIAS2 SIPM2  ...  BIAS12 SIPM12           │   24 jacks (2/ch)
   │                                                         │
   │   ch1 → ch2 → ... → ch12   (12 identical cell rows,     │
   │   front-end → CR-112 → CR-200 → CR-210 → THS3491 buf)   │
   │                                                         │
   │  TEST1 OUT1  TEST2 OUT2  ...  TEST12 OUT12              │   24 jacks (2/ch)
   └──────────────── OUTPUT edge (~334.7 mm) ───────────────┘
     short edge: J_PWR (supply in) + J_DAISY (raw rails out)
                 — both 3-pos 5.08 mm Phoenix screw terminals
```

- **Input edge:** 24 jacks = each channel's `BIAS` + `SIPM`, paired by channel.
- **Output edge:** 24 jacks = each channel's `TEST` (charge-injection input) + `OUT_50`
  (50 Ω output), paired by channel.
- Keep each channel's front-end node (`BIAS`→filter→`FE`→`Cc`→CSP) compact and its
  `OUT_50` trace short; the channel flows straight across the board input-edge →
  output-edge.

## Mounting

- **4× M3** holes (`MountingHole:MountingHole_3.2mm_M3`), one near each corner, inset for
  standoffs to the case **bottom cover**. Keep ≥5 mm from board edge and clear of jack
  courtyards.
- Standoff height 5–10 mm (sets the height budget above; 1U usable interior 40.09 mm).

## Net-class / HV note for layout

- `hv_bias` (the per-channel `BIAS_IN`/`SIPM`/`FE` nets, ≤ 70 V) gets **0.6 mm
  clearance/creepage** (0.4 mm track); keep these off plane edges and don't run signals
  under them.
- `OUT` is `signal` class (≈50 Ω); short, ground-referenced.
- See [../docs/hardware/pcb-design-rules.md](../docs/hardware/pcb-design-rules.md).

## Open (confirm before fab)

- Standoff pattern / M3 hole coordinates against the RM1U1908VBK bottom cover; final panel
  slot position and height so the two MCX rows clear the ~340 × 7 mm cut-outs.
- `J_PWR` / `J_DAISY` exact positions; cable strain relief for the 48 MCX leads at the
  panels.

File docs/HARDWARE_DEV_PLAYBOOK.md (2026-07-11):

# Hardware development with Claude — a playbook

> A guide for starting a **new board** with Claude Code. Written after building the
> single-channel Cremat amplifier (schematic capture → parts sourcing → simulation →
> layout → autoroute → review) so the next board doesn't have to rediscover any of it.
>
> Companion docs: [KICAD_WITH_CLAUDE_CODE.md](KICAD_WITH_CLAUDE_CODE.md) (the file-as-text
> method), [FREEROUTING.md](FREEROUTING.md) (autoroute recipe),
> [development-plan.md](development-plan.md) (the track model in practice).

---

## 0. The loop

Everything below is a variation on one loop:

```
author the file as text  →  validate headless (kicad-cli)  →  render it  →  LOOK at it  →  fix
```

The three failure modes map exactly onto the three checks:

| Failure | Caught by |
|---|---|
| Wrong connectivity | `kicad-cli sch erc` + **netlist-membership diff** (§4.2) |
| Wrong geometry / clearance | `kicad-cli pcb drc` |
| Wrong-but-legal (unreadable, mislabeled, wrong part) | **render → rasterize → look**, and a human/adversarial review |

ERC will happily pass a wrong-but-legal schematic. DRC will happily pass an ugly-but-legal
board. **Never skip the "look at it" step** — and never trust a downscaled thumbnail; crop
and inspect at real resolution (§4.4).

---

## 1. Why this works

1. **Every KiCad file is plain-text S-expression.** `.kicad_sch`, `.kicad_pcb`, `.kicad_sym`,
   `.kicad_mod` — all readable/writable with ordinary file tools or a Python generator.
   `.kicad_pro` is JSON.
2. **`kicad-cli` is a headless test runner.** ERC, DRC, netlist export, BOM, SVG/PDF render,
   gerbers, STEP. This is your feedback loop; it replaces "look at the editor."
3. **`pcbnew` is a real Python API** (PCB only — Eeschema has none). Use it for placement,
   DSN/SES import-export, zone fills.

So: generate the schematic from a **single source of truth** script, gate it with `kicad-cli`,
and hand only the genuinely-human steps (placement aesthetics, dense routing, part choices) to
a person.

---

## 2. The parallel-development model

### 2.1 Tracks, owners, contracts

Split the board into **tracks**: self-contained units with explicit inputs, deliverables, and a
definition-of-done. Each track publishes an **`INTERFACE.md`** — the contract downstream tracks
integrate against *without reading the track's internals*.

A worked split (this repo's Phase 1 ran tracks 1–4 fully in parallel):

| Track | Owns | Parallel? | Deliverable |
|---|---|---|---|
| 0 · Coordinate | spec, iron rules, cross-track decisions, gates | throughout | `development-plan.md`, decision list |
| 1 · Parts / datasheets / BOM | `models-bom/` | ✅ | `*-bom.csv` + sourcing report |
| 2 · Circuit & simulation | `sim/` | ✅ | SPICE decks + figures-of-merit |
| 3 · Topology / reference integration | `docs/hardware/` | ✅ | channel topology |
| 4 · Mechanical / connectors | `mechanical.md` | ✅ | footprints, board outline |
| 5 · Schematic capture | `design/gen_sch.py`, `*.kicad_sch` | ← needs 1–4 | ERC-0 schematic |
| 6 · PCB layout + autoroute | `design/gen_pcb.py`, `*.kicad_pcb` | ← needs 5 | DRC-0 board |
| 7 · Fabrication | `fabrication/` | ← needs 6 | gerbers, BOM, CPL |

Phase-1 tracks have no dependencies on each other. Phase-2 (5→6→7) is strictly serial.

### 2.2 Running tracks as parallel Claude agents

This is the part that pays off. Launch a background agent per independent track. **The single
rule that makes it safe: strict file ownership.**

When you brief a parallel agent, give it:

1. **An explicit allowlist of files it may write.**
2. **An explicit denylist** — name the files another agent is actively editing.
   > *"DO NOT edit `design/gen_sch.py` or any `.kicad_sch` — another session is rewriting it.
   > If you find a part that must be swapped, RECORD the recommendation; don't change the design."*
3. **The context files to read first** (iron rules, the relevant `INTERFACE.md`).
4. **A self-contained deliverable spec** — its final message is the only thing you get back.
5. **Citation requirements** for anything factual: *"every lifecycle/stock claim MUST cite a URL
   you actually fetched; if a page is unreachable say so rather than guessing."*

**It works.** The parts-sourcing agent that ran alongside the schematic redraw found a latent
bug nobody had noticed: the 0.1 µF decoupling cap's Digi-Key PN was for an **0603** part sitting
in an **0805** footprint. Three other PNs were stale or malformed. That's exactly the kind of
tedious, high-value, embarrassingly-parallel work to farm out.

### 2.3 What parallelizes, and what doesn't

| Parallelize | Keep serial / single-author |
|---|---|
| Datasheet hunting, lifecycle/stock checks, BOM sourcing | Schematic layout (one coherent artifact) |
| Independent simulation decks | PCB placement (global consistency) |
| **Adversarial review** — fan out reviewers on different regions/lenses | Anything with a global invariant |
| Per-block research | |

Do **not** fan out "write the schematic in 5 pieces and merge." A schematic is one tightly
coupled artifact: seams, styling, and overlaps don't merge cleanly. Author it once; **fan out
the verification instead**.

### 2.4 Adversarial review (high value, cheap)

After the schematic renders cleanly, spawn independent reviewers — one per sheet region, plus
one design-fidelity checker reading the netlist against the circuit docs. Tell them:

> *"Connectivity is already proven identical (ERC 0, netlist diff clean). Do NOT re-check nets.
> Your only job is whether the DRAWING is readable. Be adversarial and specific. If a region is
> clean, say so — do NOT invent problems."*

That pass caught a **systemic** defect I'd missed: every decoupling cap's value string was drawn
straight through its GND symbol, because the generator placed `Value` at `(x+2, y+5.5)` — the
exact spot the GND symbol occupies. One generator fix, ~10 instances corrected.

---

## 3. Track playbooks

### 3.1 Parts, datasheets & BOM

- One row per reference designator; a `Populate_Default` column (`FIT`/`DNP`) is the **single
  source of truth** for build variants. Keep design source and BOM in sync — a DNP flag that
  disagrees with the schematic is a fab bug.
- Verify **lifecycle status** (Active / NRND / LTB / Obsolete) *and* orderability, with a cited
  URL per claim. Parts rot: this board's charter part (EL5167) was obsolete, and its bias cap
  went NRND mid-project.
- **Sanity-check physical size against the assembly philosophy.** If the board is deliberately
  0805-and-up for hand assembly, a SOD-123 diode (≈2.7×1.6 mm) is *smaller than an 0805* —
  wrong answer even though it's "a real part." Prefer SMA/DO-214AC or a leaded DO-41.
- Prefer parts you can still buy in the qty you need at the *scaled* count (×12 channels).

### 3.2 Simulation

Pattern used here (LTspice, batch mode):

```
sim/
  decks/    *.cir  (top-level decks) + vendor .sub/.lib models + models.inc
  models/   vendor SPICE downloads, kept with their source URL
  scripts/  ltspice_raw.py (raw parser) + analyze_*.py (FoM extraction)
  data/     *.raw, *.log, *_fom.json  (generated)
```

- **Use the vendor's official model** and record where it came from (e.g. TI SBOMAN4 for the
  THS3491, Cremat's own CR-200/CR-210 models). Don't hand-roll an op-amp macromodel if the
  vendor ships one.
- Run headless: `LTspice.exe -b -Run deck.cir` → parse the `.raw` → emit a **figures-of-merit
  JSON/CSV**, not just a plot. FoM files are diffable; plots aren't.
- Let the sim **pin component values** and record it in the design source. Here the CFA feedback
  resistor (`Rf = Rg = 976 Ω`) was validated against TI's model, and that provenance is a code
  comment in the generator.
- KiCad bundles `ngspice.dll` if you'd rather stay in-tree; LTspice was used here.

### 3.3 Schematic capture

Author it with a **generator script** (`gen_sch.py`) so it's reproducible. See §5 for the
gotchas that will otherwise cost you a day.

Structure that worked:

- `PARTS{}` — role → (value, MPN, manufacturer, distributor PN). Real-part metadata.
- `SPEC{}` — role → (lib_id, footprint, dnp, `{pin: net}`, `(x, y, rotation)`).
- `ROLES[]` — a fixed order that determines reference designators (`R1`, `C1`, …). Keep the order
  stable so refs don't churn on unrelated edits.
- `layout()` — places symbols, then wires them **by pin lookup** (`P(role, pin)`), never by
  hand-typed coordinates. Wires then always land exactly on pins.
- A **coverage self-check**: assert every declared pin has a net (wire endpoint, label, power
  symbol, or no-connect). Catches "I forgot to ground that cap" before ERC does.
- Deterministic `uuid5` UUIDs so re-runs reproduce the file byte-for-byte.

**Readability is a design requirement, not a nicety.** A netlist-correct schematic that a human
can't review is not done. Draw a left→right signal spine, bank the decoupling above (+rail) and
below (−rail), and wire the signal path pin-to-pin. Use net labels for rails and power symbols
for globals — don't route 12 V across the sheet.

### 3.4 PCB layout & autorouting

The verified recipe (from [FREEROUTING.md](FREEROUTING.md)):

```bash
PY="C:/Program Files/KiCad/10.0/bin/python.exe"
"$PY" design/gen_pcb.py        # board outline, stackup, footprint placement
# --- clean the placement FIRST: no overlapping copper (see below) ---
"$PY" design/export_dsn.py     # pcbnew.ExportSpecctraDSN -> .dsn
java -jar freerouting-2.2.4.jar -de board.dsn -do board.ses    # Java 21+ (25 verified)
"$PY" design/import_ses.py board.ses                            # tracks back into .kicad_pcb
"$PY" design/fill_zones.py     # separate pass — see below
bash scripts/drc.sh            # the gate: 0 errors
```

Hard-won constraints:

- **Placement is the human step.** `ExportSpecctraDSN` returns `False` if any copper overlaps.
  Autorouters route; they don't fix a bad floorplan. Spread parts until DRC shows no
  `clearance`/`shorting_items`, *then* export.
- **Give the router layers.** A 4-layer board with a GND plane and a −VDC plane routed all 480
  nets; the same board on 2 layers left ~9 nets unrouted. Buy the layers.
- **Fill zones as a separate pass on the saved file.** Headless `ZONE_FILLER.Fill()` segfaults
  if you call it inline — that's why `fill_zones.py` exists.
- Hand off dense/controlled-impedance routing to a human. Do placement + constraints
  programmatically, gate with DRC.

### 3.5 Review & handoff

Export a **PDF for the reviewer** into the repo (`design/reports/*.pdf`) and regenerate it every
time the design changes. An engineer reviewing a stale PDF is worse than no review.

---

## 4. The gates

### 4.1 ERC

```bash
KCLI="C:/Program Files/KiCad/10.0/bin/kicad-cli.exe"
"$KCLI" sch erc --exit-code-violations board.kicad_sch -o reports/erc.rpt   # exit 0 == clean
```
Configure `pin_not_connected` and `label_dangling` as **errors**. A forgotten connection then
becomes a build failure instead of a silent bug.

### 4.2 Netlist-membership diff — *the most valuable tool here*

**When you refactor, redraw, or move anything, prove the circuit didn't change.** Export the
netlist before and after, and diff **net membership** (the set of `(ref, pin)` per net),
*ignoring* net names — because auto-generated names (`Net-(R1-Pad2)`) legitimately churn.

This let a complete schematic redraw — every part moved, 99 wires added where there were zero —
land with total confidence: `IDENTICAL CONNECTIVITY: 26 nets`. It also instantly localized every
bug during the rewrite (a missing junction, a dangling rail label) to the exact net.

```python
# netcmp.py — usage:  python netcmp.py before.net [after.net]
import re, sys
def parse(path):
    t = open(path, encoding="utf-8").read(); nets = {}
    for m in re.finditer(r'\(net\s+\(code\s+"?\d+"?\)\s+\(name\s+"([^"]*)"\)', t):
        start, depth, i = m.start(), 0, m.start()
        while i < len(t):
            if t[i] == '(': depth += 1
            elif t[i] == ')':
                depth -= 1
                if depth == 0: break
            i += 1
        block = t[start:i+1]
        nets[m.group(1)] = {(n.group(1), n.group(2)) for n in
            re.finditer(r'\(node\s+\(ref\s+"([^"]+)"\)\s+\(pin\s+"([^"]+)"\)', block)}
    return nets

a = parse(sys.argv[1])
if len(sys.argv) < 3:
    for k in sorted(a): print("%-16s %s" % (k, sorted(a[k])))
    sys.exit(0)
b = parse(sys.argv[2])
ca, cb = {frozenset(v) for v in a.values() if v}, {frozenset(v) for v in b.values() if v}
name = lambda n, s: next((k for k, v in n.items() if frozenset(v) == s), "?")
if ca == cb:
    print("IDENTICAL CONNECTIVITY: %d nets" % len(ca)); sys.exit(0)
print("DIFFERENCES FOUND")
for s in ca - cb: print("  only in A (%s): %s" % (name(a, s), sorted(s)))
for s in cb - ca: print("  only in B (%s): %s" % (name(b, s), sorted(s)))
sys.exit(1)
```

When you *intend* to change the circuit, the diff is still the check — you read it and confirm
the delta is **exactly** what you meant (e.g. *"`TEST_IN` gained R5, `TEST_N` is gone"*).

### 4.3 DRC

```bash
"$KCLI" pcb drc --exit-code-violations board.kicad_pcb -o reports/drc.json
```
Refill zones before DRC. Never commit DRC **errors**.

### 4.4 Render → rasterize → look

```bash
"$KCLI" sch export pdf board.kicad_sch -o reports/review.pdf
pdftoppm -png -r 300 reports/review.pdf out          # MiKTeX ships pdftoppm
# then crop regions with PIL and actually inspect them
```
A full-sheet thumbnail hides everything. **Crop to a region at 200–400 DPI.** Text overlap,
strikethrough, merged labels, and missing junction dots are only visible at real resolution.

---

## 5. KiCad-as-text: empirically verified gotchas

Every one of these was confirmed by experiment (a throwaway probe schematic + netlist/render),
not guessed. Re-verify with a probe if you're on a different KiCad version.

**Geometry**
- **Pin transform under rotation** (schematic is Y-down, symbol libs are Y-up). For a symbol at
  `(at X Y θ)` and library pin `(px, py)`:
  ```
  sheet = ( X + px·cosθ − py·sinθ ,  Y − (px·sinθ + py·cosθ) )     # θ CCW
  ```
  Verified for θ ∈ {0, 90, 180, 270} — lands on the correct **pin number**, not just position.
- **Property text angle = symbol rotation + property angle.** To keep `Reference`/`Value`
  horizontal on a rotated part, set the property's own angle to `(180 − rot%180) % 180`.
  Property *position* is absolute (it is **not** rotated with the symbol).

**Connectivity**
- **A wire ending on another wire's interior (a T) does NOT connect without a junction.**
  Auto-place them: a junction is needed at `p` when
  `wire_ends(p) + 2·wires_passing_through(p) + pins(p) ≥ 3`.
- **`PWR_FLAG` and power symbols must sit on a wire *endpoint*, or coincide with a component
  pin.** Mid-wire they are silently unconnected → `pin_not_connected` + `power_pin_not_driven`.
- **A net label must be anchored *on* the wire.** `justify` only moves the text, not the
  attachment point. An off-wire label dangles and the net gets auto-named.
- **Power symbols contain a hidden `power_input` pin.** So any net carrying a power symbol needs
  a `PWR_FLAG` somewhere, or ERC reports "not driven." Connector pins are `passive` and need no
  flag. Filtered rails behind a series R each need their own flag.

**Rendering**
- **`(junction ... (diameter 0) ...)` exports as zero-size** — the connection dots vanish from
  `kicad-cli`'s PDF. Set an explicit diameter (`0.9144` = KiCad's classic 36 mil).
  *This is invisible until a reviewer asks "why aren't the connections shown?"*
- **Don't put `Value` below a vertical 2-pin part** — that's where its GND symbol lives. For
  `rot % 180 == 0` passives, stack `Reference`/`Value` to the **side** at mid-height; for
  horizontal ones, above/below is fine.
- **Hide verbose value text** on connectors and `PWR_FLAG`s. `"MCX edge jack 50R"` on four jacks
  is pure clutter; the refdes and net label already say it.

**Misc**
- `python` is usually **not on PATH** — use KiCad's bundled interpreter (§7).
- Deterministic `uuid5` over a fixed namespace → re-running the generator produces no spurious diff.

---

## 6. Working with the human

- **Restate the topology in ASCII and get a nod before you edit.** Two round-trips were burned on
  this board: "remove the 0.1 µF" (bias cap vs. power-rail bypass — I removed the wrong one), and
  the Zener protection (dead-end `rail→R→zener→GND` shunt vs. the intended
  `connector→R→rail`, `rail→zener→GND`). Both would have been caught by five lines of ASCII art.
- **`TBD` is a first-class value.** Place the part, wire it, mark the value `TBD`, leave it out of
  the BOM, and ask. Don't invent a resistor value to make a schematic look finished.
- **Surface part swaps, don't perform them silently.** An NRND part with an identical active
  drop-in is still the owner's call — recommend, then apply on a yes.
- **Say what changed and what you verified.** "ERC 0, netlist identical, PDF refreshed" beats
  "done."
- **Don't commit** unless asked. Leave changes in the working tree for review.

---

## 7. Toolchain reference (Windows, KiCad 10)

```bash
KCLI="C:/Program Files/KiCad/10.0/bin/kicad-cli.exe"   # not on PATH
PY="C:/Program Files/KiCad/10.0/bin/python.exe"        # bundled; has pcbnew + PIL
STOCK="C:/Program Files/KiCad/10.0/share/kicad/symbols"
FPS="C:/Program Files/KiCad/10.0/share/kicad/footprints"
pdftoppm                                              # from MiKTeX; rasterize PDFs
java -jar freerouting-2.2.4.jar                       # needs Java 21+ (25 verified)
```

| Need | Command |
|---|---|
| ERC | `"$KCLI" sch erc --exit-code-violations f.kicad_sch -o erc.rpt` |
| Netlist | `"$KCLI" sch export netlist f.kicad_sch -o f.net` |
| Review PDF | `"$KCLI" sch export pdf f.kicad_sch -o review.pdf` |
| DRC | `"$KCLI" pcb drc --exit-code-violations f.kicad_pcb -o drc.json` |
| Gerbers | `"$KCLI" pcb export gerbers --output fab/ f.kicad_pcb` |
| Inspect a stock symbol | `"$PY" -c "…"` — read `$STOCK/Device.kicad_sym`, grep the `(pin …)` blocks |

**Always introspect a symbol before using it** — pin numbers and names are not what you assume.
`Device:D_Zener` is pin 1 = **K** (cathode), pin 2 = **A** (anode). `Device:R` at rot 0 is pin 1
top, pin 2 bottom. Screw-terminal pins are `passive`.

---

## 8. Anti-patterns

- Trusting a downscaled render. Crop and look.
- "ERC passes, ship it." ERC does not check design intent.
- Fanning out schematic *authoring* across agents. Fan out review instead.
- Letting the BOM and the design source disagree on values, MPNs, or DNP flags.
- Hand-typing wire coordinates instead of looking up transformed pin positions.
- Adding a net label to name an internal node that's already defined by a wire — you'll either
  dangle it or collide with an existing net name.
- Renaming/removing a part from the middle of the `ROLES` list without expecting every
  downstream refdes to renumber.

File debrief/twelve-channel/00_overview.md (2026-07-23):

# 00 — Overview

| | |
|---|---|
| **Date** | 2026-07-22 |
| **Role slug** | `twelve-channel` |
| **Repo root** | `C:\Users\darro\OneDrive - Yale University\Desktop\multi-channel-cremat-amplifier` |
| **Git commit** | `42b380037f07de6acff862079fc07dfe6718b660` ("Fix schematic connectivity: netclasses were missing their SCHEMATIC fields") `[verified-run]` |
| **Host** | Windows 11 Home 10.0.26200, PowerShell 5.1 + git-bash `[verified-run]` |

---

## The project

A **12-channel SiPM charge-sensitive preamplifier / Gaussian shaper** board for a neutrino-physics
lab. Each channel is: MCX coax bias input → optional RC bias filter → AC-coupling cap → **Cremat
CR-112** charge-sensitive preamp (SIP-8 module) → **CR-200-1µs** Gaussian shaper → optional
**CR-210** baseline restorer → optional **THS3491** ×2 buffer → 49.9 Ω back-terminated MCX output.
Twelve of those, plus one shared bipolar (±12 V) power-entry section with PTC + Schottky
reverse-protection and bulk electrolytics.

What made it complex, in rough order of pain:

1. **Repetition at scale.** 12 identical channels → 468 footprints, 464 schematic symbols, 1290
   pads, 271 nets. Everything had to be *generated*, never hand-drawn, or it would never stay
   consistent. `[verified-run]`
2. **Mixed-technology parts.** Through-hole SIP-8 sockets (Cremat modules plug in), edge-mounted
   MCX jacks that straddle a routed slot in the board outline, 0805 SMD passives, and a
   SOIC-8-EP op-amp — in one board, one BOM, one assembly flow.
3. **48 edge-mount connectors.** The MCX footprint carries an edge notch; the board outline has
   to be *cut* by 24 notches per long edge, and DRC's edge-clearance rule has to be waived for
   exactly that footprint via a custom `.kicad_dru` rule.
4. **Populate-or-bypass variants.** Two optional blocks (CR-210 BLR, THS3491 buffer) are
   DNP-by-default with 0 Ω bypass jumpers. The BOM, the CPL and the DRC all have to agree about
   which of two mutually exclusive paths is fitted.
5. **Mechanical coupling.** The board width is a *function of* the rack enclosure's internal
   depth, because the MCX barrels must reach through front and rear bulkheads.

The board reached fabrication-ready: DRC 0 violations / 0 unconnected, ERC 0, gerbers + drill +
JLCPCB BOM/CPL generated, DigiKey hand-solder BOM priced, enclosure selected. `[verified-run]`

---

## The scope I owned

I was the **final-board session**: everything under `final-board/twelve-channel/`.

- `design/gen_sch.py` — generate the 12-channel hierarchical schematic (root + 12 child sheets)
- `design/gen_pcb.py` — generate the PCB by tiling the routed single-channel row ×12, plus the
  common power section, board outline with MCX notches, plane zones, mounting holes, `.kicad_dru`
- `design/fill_zones.py`, `design/polish_silk.py` — post-processing passes
- `models-bom/gen_bom.py`, `models-bom/gen_purchasing.py` — BOM + purchasing/sourcing documents
- Fab output generation (gerber/drill/CPL/BOM for JLCPCB), enclosure + ordering documentation
- The library work: local `cremat.pretty` footprints and `cremat.kicad_sym` symbols
- **All of the connectivity debugging** described in `06_gotchas.md` — the single most expensive
  episode of the project

I also **edited the single-channel generator** (`integration/single-channel/design/gen_sch.py`,
694 lines) extensively, because the 12-channel generator imports it as a module and reuses its
`layout_channel()` / `layout_power()` / symbol-emitter functions. That file is therefore
`[shared]` territory: I own the schematic-drawing internals I changed; the original single-channel
design intent is the other session's. `[verified-run]` on file sizes.

## The other session's territory

`[recalled]` — I did not verify these and should not be trusted on details:

- The **single-channel cell** itself: circuit topology, part selection, the reviewed
  `integration/single-channel/design/channel.kicad_pcb` that my tiler clones. It was routed and
  DRC-clean before I touched it.
- **SPICE simulation** under `sim/` — pole-zero cancellation, shaping-time verification, the
  trimpot P/Z procedure. I never ran it. `sim/netlists/` exists on disk. `[verified-artifact]`
- The **earlier sub-boards** under `chips-board/` (csp-cr112, shaper-cr200-cr210) which were the
  Phase-A proving grounds for the Cremat symbols and footprints.
- **FreeRouting autorouting** of the single channel (`docs/FREEROUTING.md`,
  `export_dsn.py`/`import_ses.py`). I inherited its routed output; I re-ran the DSN/SES round-trip
  only once and mostly worked from the already-routed row. `[shared]`

Separately: during the final debugging I consulted a **different Claude session working on a
different board** (`Desktop\low-frequency-amplifier`, a ramp-amp/AA-filter project). That session
served as a *known-good reference implementation* of a generated hierarchical KiCad project, and
diffing against it eliminated four wrong hypotheses in one pass. Its files are quoted in
`06_gotchas.md` where they were decisive. `[verified-artifact]` — I read its files directly.

---

## The pipeline from my seat, in one line

**Single-channel routed cell (given) → generate 12-ch hierarchical schematic → export netlist →
tile the routed cell ×12 + place/route the common power section → fill zones → DRC/ERC/parity
gates → 3D render + PDF for human review → fab outputs (gerber/drill/CPL/BOM) → purchasing docs.**

The loop that actually dominated wall-clock was not any of those stages. It was
**generate → human opens it in the KiCad GUI → human sees something the automated gates cannot
see → fix generator → regenerate**. Every gate I had (`kicad-cli sch erc`, `kicad-cli pcb drc`,
netlist export, pcbnew pad-net comparison) is blind to a whole class of defect, and the human
eye in the GUI was the only instrument that caught them. See `06_gotchas.md`.

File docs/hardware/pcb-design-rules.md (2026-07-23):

# PCB Design Rules

Net classes, trace widths, clearances, and HV considerations for the 12-channel amplifier.
Modeled on the reference board and on `ets-breakout`'s net-class scheme, with the addition
of an explicit **HV bias** class because this board now carries the per-channel detector
bias nets (12× `BIAS_IN`, ≤ 70 V).

Set these in the KiCad project (`*.kicad_pro`) so they apply automatically by net name.

---

## Net classes

### `Default`
| Parameter | Value |
|---|---|
| Track width | 0.20 mm (~8 mil) |
| Clearance | 0.20 mm |
| Via Ø / drill | 0.6 / 0.3 mm |

Low-current analog/logic-level interconnect between modules.

### `power` — `+VDC`, `-VDC`, `GND`
| Parameter | Value |
|---|---|
| Track width | 0.5 mm (~20 mil) min, wider on the plane feeds |
| Clearance | 0.2 mm |

Wider for low IR drop; prefer a poured plane for `GND`.

### `hv_bias` — `BIAS_IN` and per-channel filtered bias / `SIPM` (NEW)
| Parameter | Value |
|---|---|
| Track width | 0.4 mm (current is tiny; width is for robustness/HV) |
| Clearance / creepage | **set from the SiPM bias voltage** — see table below |

Assign by net-name pattern: `BIAS*`, `SIPM*`, and the front-end node nets. This is the
only HV class; give it the most clearance and keep it off plane edges.

### `signal` — amplifier I/O, `OUT`
| Parameter | Value |
|---|---|
| Track width | ~0.33 mm signal (etch / current robustness; **not** impedance-tuned — the outer nets are grounded coplanar, see Stackup) |
| Clearance | 0.2 mm |

Use for `OUT` (50 Ω-driven). Match the reference board's pattern of a dedicated class for
the coax-driven nets. This board is **not** ordered as controlled impedance — see
[Stackup](#stackup) for why transmission-line effects are negligible at the ~1 µs pulse
bandwidth.

---

## HV clearance / creepage (per-channel bias nets)

The detector bias sets the minimum spacing on the `hv_bias` class. **Bias is confirmed
≤ 70 V**, so the `hv_bias` class is fabbed with **0.6 mm clearance/creepage** (with the
0.4 mm track above); parts (`Cc`,`Cf`) stay rated 100 V for margin.

| Bias voltage | Min clearance/creepage (uncoated FR4, guide) |
|---|---|
| ≤ 50 V | 0.5 mm |
| **≤ 70 V (this board → `hv_bias` class)** | **0.6 mm (as fabbed)** |
| ≤ 250 V | 2.0 mm |

These are conservative starting points (IPC-2221 B internal/external, no conformal
coating). Tighten only with justification. Enforce via the `hv_bias` clearance and KiCad's
**creepage** DRC rule (treat creepage/clearance violations as **errors**, as the reference
project does). The final board's live DRC confirms the 0.6 mm `hv_bias` clearance with
**0 errors**.

---

## Guard / sensitive node

- The **front-end node** (`BIAS_IN→filter→node→Cc→CSP input`) is the high-impedance,
  noise-sensitive node. Keep it small; consider a `GND`-referenced guard or a local pour
  back-off, following the reference board and `ets-breakout`'s guard-ring practice.
- Keep `Cc` and the CSP input pads tight together to minimize the exposed HV-to-amp node.

---

## DRC severities (match the reference project)

**Errors (block fab):** clearance, creepage, copper-to-edge, annular ring, hole/hole &
hole-to-copper, drill out of range, courtyard overlap, invalid outline, items on disabled
layers.

**Warnings:** connection width, copper slivers, duplicate/extra/missing footprints,
silk overlaps.

**Gate:** `kicad-cli pcb drc` must report **0 errors** before generating fab outputs — the
same gate `ets-breakout` enforces.

---

## Stackup

### Why four layers (it is **not** for impedance control)

Asked directly, since 2-layer is cheaper and faster: the fourth layer here buys **plane-based
power/return distribution**, not controlled impedance. Impedance is explicitly *not* controlled on
this board — see the bullets below the table.

The as-routed board makes the case numerically. Of 1290 pads, **464 are `GND` / `+VDC` / `-VDC`**
(364 / 50 / 50), yet those three nets account for only **490 mm of track in total** across a
213 × 335 mm board — because each of those pads drops through a via straight onto its plane
(240 GND vias, 50 per rail). **A 2-layer build has to route all 464 of those connections as
tracks**, in the same two layers that already carry 12 analog signal chains and 12 HV bias nets.

Three reasons that matters here specifically:

1. **The return path is the signal.** A CSP is a charge integrator: it sums *every* current
   arriving at its input node. Return current from a neighbouring channel flowing through shared
   ground metal appears at that input as charge — i.e. as a pulse indistinguishable from a real
   SiPM event. A solid, unbroken **GND plane (In1) directly beneath the analog chain** gives each
   channel a low-impedance image return under its own trace, so 12 channels do not share return
   metal. On 2 layers the bottom-side ground must be sliced by rail routing; every slice forces a
   detour and re-introduces exactly the shared impedance we are trying to avoid. With 12 channels
   on one board, inter-channel crosstalk is the dominant systematic risk.
2. **The rails are bipolar and go everywhere.** Both `+VDC` **and** `-VDC` must reach all 12
   channels. That is two more distribution networks on top of ground. Two copper layers cannot
   hold GND + two rails + 12 signal chains + 12 HV bias nets and leave the ground solid — there
   is no arrangement where it survives.
3. **HV bias competes for the same space.** The 12 bias nets are on the `hv_bias` class
   (0.6 mm clearance, 0.4 mm track). Their creepage keep-outs consume routing channels on the
   outer layers; taking away two layers makes the crowding worse precisely where clearance is a
   safety rule rather than a preference.

Cost check: at this board size and a small build quantity, JLC's 4-layer adder is small in
absolute terms and far below the cost of one respin. The 4-layer version is already routed and
DRC-clean, so the 4→2 conversion would also be a full re-layout, not a stackup swap.

### The ordered stack

Fabbed at **JLCPCB on their standard 4-layer 1.6 mm stackup `JLC04161H-7628`** — a **normal,
non-impedance-controlled** build:

| Layer | Copper | Assignment | Dielectric below |
|---|---|---|---|
| **L1 (F.Cu)** | 1 oz | signal / pour | 0.2104 mm **7628 prepreg** (Dk ≈ 4.4) |
| **L2 (In1)** | 0.5 oz | **GND plane** | 1.065 mm **core** (Dk ≈ 4.6) |
| **L3 (In2)** | 0.5 oz | **−VDC plane** | 0.2104 mm **7628 prepreg** |
| **L4 (B.Cu)** | 1 oz | **+VDC pour** | — |

Total ≈ 1.6 mm. A solid **GND plane (In1)** sits directly under the outer signal layers for a
continuous return reference under the analog chain.

- **Do NOT order controlled impedance.** The fastest signal on the board is a ~1 µs Gaussian
  pulse (knee ≈ 300–350 kHz); a quarter-wave in FR-4 at that bandwidth is ~100 m — roughly
  1000× any trace here — so reflections / ringing / mismatch are negligible. Controlled
  impedance would only add cost, lock the stackup, and tighten the design rules for zero
  benefit. Order as a **normal (non-impedance) 4-layer** build.
- **The outer traces are grounded coplanar (GCPW), not microstrip.** Every F.Cu signal runs
  inside the GND pour *and* over the In1 GND plane, so the coplanar side grounds add capacitance
  and pull the impedance **below** a microstrip of the same width — a "microstrip 50 Ω" width
  would read < 50 Ω here. Because we do **not** order controlled impedance (slow, sub-MHz analog
  — see above), the exact width is immaterial: `signal` stays **0.33 mm for etch / current
  robustness**, not for a target impedance. If impedance ever mattered, model it as **GCPW**
  (trace width **and** the coplanar gap, plus the plane below) and **order controlled impedance**
  so JLC tunes it to their etched stack — do not hand them a bare microstrip width, which ignores
  the surrounding ground.

---

## Copper zones and pad connection (thermal relief)

Four zones, filled as a separate pass by
[`fill_zones.py`](../../final-board/twelve-channel/design/fill_zones.py) (an in-memory
`ZONE_FILLER.Fill()` during board construction segfaults headless):

| Layer | Net | Priority | Filled area |
|---|---|---|---|
| `F.Cu` | `GND` | 2 | 53 295 mm² |
| `GND.Cu` (In1) | `GND` | 0 | 65 389 mm² |
| `PWR.Cu` (In2) | `-VDC` | 0 | 63 166 mm² |
| `B.Cu` | `+VDC` | 1 | 65 363 mm² |

**Pad connection = `THERMAL` (spoke relief), board-wide.** Gap 0.5 mm, spoke width 0.5 mm.

This was a **fix**, not a default: the zones had been left on `ZONE_CONNECTION_NONE`, which
isolates the pour from *every* pad. The GND pour then contributed nothing to the ground return —
all GND connectivity went via tracks and vias, so DRC still reported 0 unconnected and the defect
never surfaced in any automated check. Switching to `THERMAL` both restores the pad-to-pour ties
and keeps them solderable.

**Why thermal spokes rather than solid (`FULL`) connections:** **218 GND pads on this board are
hand-soldered** — 120 SIP-8 socket pins for the Cremat modules, 96 MCX shield pads, and the
2-pin screw terminal (the board reports 122 through-hole GND pads; the MCX shields are SMD-attribute
but still hand-assembled). Soldering those directly into a 65 000 mm² copper plane wicks heat away
faster than a hand iron can replace it, giving cold joints and lifted pads. Spokes are the standard
answer and cost essentially nothing here:

- **Current:** rail draw is milliamps per channel; a 0.5 mm spoke is orders of magnitude more
  copper than needed.
- **Inductance:** four spokes add ~1–2 nH. At a ~350 kHz knee that is <10 µΩ of reactance —
  irrelevant. (On a fast digital board this trade would go the other way.)

Regenerate with:

```bash
"C:/Program Files/KiCad/10.0/bin/python.exe" final-board/twelve-channel/design/fill_zones.py
```

`fill_zones.py` first checks that the `.kicad_pro` still holds its netclasses and restores them if
a GUI save has flattened the file — otherwise the fill silently ignores the `hv_bias` clearance and
a subsequent DRC passes vacuously.

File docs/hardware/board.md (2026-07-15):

# Board

Board-level design of the 12-channel amplifier: how the channel cell is replicated, how
power and bias are distributed, and the connector / mechanical intent.

**KiCad project (to be created by the hardware track):** `hardware/multi-channel-cremat-amplifier.kicad_pro`
**Channels:** 12 (one hierarchical sheet, instantiated 12×)

---

## Schematic structure

Mirror the reference board's hierarchy:

```
root sheet  (power entry, bias distribution, 12× channel instances)
 └── channel.kicad_sch   ×12   (the cell documented in channel.md)
```

The reference root (`reference/cremat-x6-board/cremat-board.kicad_sch`) instantiates
`channel.kicad_sch` six times (`ch0…ch5`). Do the same with **twelve** instances
(`ch0…ch11`). Keep the per-channel `BIAS_IN`, `+VDC`, `-VDC`, `GND` as global nets so a
single distribution network on the root sheet feeds every channel.

---

## Power distribution

| Rail | Entry | Distribution |
|---|---|---|
| `+VDC` / `-VDC` (±Vs) | Power connector (screw terminal or header) | Star/bus to each module; **bulk** electrolytics at entry (e.g. 10 µF + 100 µF per rail), **local** decoupling at every Cremat module and op-amp |
| `GND` | same connector | Solid ground plane; common reference for supply and bias |

> **`BIAS_IN` is per-channel, not a shared rail.** Each channel has its own `BIAS_IN` MCX
> jack feeding only its own bias filter — see [Connectors](#connectors). There is no
> board-wide bias distribution net; the bias supply is fanned to the 12 jacks externally.

- The analog supply (`±Vs`, `GND`) **is** shared across all channels.
- Decoupling values follow the reference (per-rail 0.1 µF / 1 µF / 10 µF near modules),
  resized to 0805 where the voltage rating allows.
- Keep each **`BIAS_IN<n>` net away from the ground plane edges** and honor HV creepage
  (≤ 70 V → 0.6 mm, [pcb-design-rules.md](pcb-design-rules.md)).

---

## Connectors

| Connector | Qty | Purpose | Part |
|---|---|---|---|
| `BIAS_IN` (per channel) | 12 | HV detector bias in (≤ 70 V), one per channel | **MCX edge-mount, TE Linx `CONMCX013`** (DK `343-CONMCX013-ND`) |
| `SIPM` (per channel) | 12 | Coax to each detector (DC bias + signal) | same `CONMCX013` |
| `TEST` (per channel) | 12 | Per-channel test-pulse injection / monitor | same `CONMCX013` |
| `OUT_50` (per channel) | 12 | 50 Ω shaped output to DAQ | same `CONMCX013` |
| `J_PWR` (supply in) | 1 | Analog supply in (±Vs, GND) | **3-pos 5.08 mm Phoenix screw terminal** |
| `J_DAISY` (rails out) | 1 | Raw ±Vs / GND daisy-chained to the next 1U box | **3-pos 5.08 mm Phoenix screw terminal** |

- **All four per-channel jacks are the same MCX part — `CONMCX013` — so 48 MCX/board.**
  50 Ω, female, board-edge cutout, SMT. Track 1 pulls its datasheet/footprint/3D model
  ([component-libraries.md](component-libraries.md)).
- **Two power terminals, not one:** `J_PWR` takes the supply in and `J_DAISY` passes the raw
  rails out to the next 1U box — the power connector is not the only shared connector.
- Group each channel's `BIAS_IN` + `SIPM` + `TEST` + `OUT_50` near its cell to keep the bias
  node and the output trace short. 48 edge jacks dominate the board outline and the panel layout.

---

## Layout intent

1. **Channel pitch = module height.** The Cremat SIP-8 modules stand vertically; lay the
   12 cells out on a regular pitch so the modules form neat rows (as on the reference
   board) and the coax jacks line the edges.
2. **Front-end node is the sensitive node.** Keep `BIAS_IN→filter→node→Cc→CSP` compact;
   minimize the high-impedance amplifier-input copper. Consider a guard around it
   (the reference and `ets-breakout` both guard sensitive analog nodes).
3. **Bias-net isolation.** Route each `BIAS_IN<n>` and its filtered bias as the `hv_bias`
   net class with extra clearance (≤ 70 V → 0.6 mm); do not run signal traces under it.
4. **Output side is 50 Ω.** The `49.9R` (with the THS3491 buffer DNP-bypassed by default)
   drives the coax; keep `OUT` traces short and reference them to ground. The board is **not**
   ordered controlled-impedance — the ~1 µs pulse bandwidth makes transmission-line effects
   negligible (see [pcb-design-rules.md](pcb-design-rules.md)).
5. **Ground plane** continuous under the analog chain for low-noise return.

---

## Mechanical (D5 — 1U vented rack case, one board per case, slot-through panels)

- **Board outline:** **213.2 × 334.7 mm**, 4-layer — **one** 12-channel board per case.
- **Enclosure:** **Hammond RM1U1908VBK**, a **1U vented** rack case (1U outer ≈ 44.45 mm).
  Usable interior: **196.85 mm deep × 40.09 mm high × 415.30 mm wide**. **One board per
  case** — boards are never stacked or set side-by-side inside one box.
- **Slot-through panel mount.** Each long (334.7 mm) board edge passes **through a
  ~340 × 7 mm milled slot** in the front/rear panel and **protrudes ~5 mm**, so the
  edge-mount MCX faces sit **~8.6 mm proud** of the panel and mate in the open (snap-on MCX).
  This is **not** a bulkhead-flush mount and **not** an open tray — the board is captured by
  the two panel slots and stands off the case **bottom cover** on M3 standoffs.
- **Height (1U):** every part — the vertical socketed Cremat SIP-8 modules, the trimpots, the
  bulk electrolytics, and the MCX + its mated cable — must fit the **40.09 mm** usable
  interior height, minus standoff height.
- **Edge jacks:** the **48 MCX** split **24 per long edge / panel** — one panel presents the
  inputs (`BIAS_IN` + `SIPM`), the other presents `TEST` + `OUT_50` — so each channel lays out
  as **input-edge → amplifier chain → output-edge**.
- **Scaling: daisy-chain, don't widen.** More channels means more boards, each in its **own
  1U RM1U1908VBK box**; **`J_DAISY`** carries the raw ±Vs / GND rails from one box to the next,
  so supplies chain box-to-box instead of sharing a backplane. **Never** two boards in one
  case, never an open rack tray, never open-air.
- This drives Track 4 (mechanical) and constrains Track 6 (layout).

> Board dimensions, exact jack placement, and the outline are defined in the KiCad PCB
> once implemented; this document is design intent, the PCB file is authoritative
> (same convention as `ets-breakout`).

---

## Bill of optional configurations (board build variants)

A given board is assembled in one configuration; the common ones:

| Build | Bias filter | CR-210 | Use case |
|---|---|---|---|
| **Full** ← *first build (D6)* | fitted | fitted | On-board bias + high-rate spectroscopy |
| **No-BLR** | fitted | bypassed | On-board bias, low rate / minimal latency |
| **External-bias** | bypassed | (either) | Clean external bias supply / external bias-tee |
| **Reference-equivalent** | bypassed | bypassed | Behaves like the original 6-ch board (×12) |

See the DNP tables in [bom.md](bom.md) for the exact populate/DNP set per variant.

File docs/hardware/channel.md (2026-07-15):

# Channel Circuit

One channel of the Multi-channel Cremat Amplifier. The board contains **12 identical
copies** of this cell. It derives from the reference per-channel sheet
[`reference/cremat-x6-board/channel.kicad_sch`](../../reference/cremat-x6-board/channel.kicad_sch)
with the bias front-end and CR-210 added (see [modifications.md](../modifications.md)).

Reference designators below are *cell-local*; the board flattens them per channel
(e.g. channel 7's preamp is `U7_CSP`). Use a hierarchical-sheet naming scheme so refs
stay unique across the 12 instances.

---

## Full schematic-level topology

```
                       ░░ bias filter (optional) ░░
  BIAS_IN ●───[ Rf1 ]──┬──[ Rf2 ]───●───────────────────●  SIPM        (coax to detector)
            │   ▲       │      ▲     │  FRONT-END NODE
            │  JP_Rf1   Cf    JP_Rf2 │                      DC-coupled: filtered bias
            │ (0R byp) │   (0R byp)  │                      reverse-biases the SiPM
            │          │             │
            │         GND            └──[ Cc ]──●  amp input        AC-coupled
            │                          (HV cap)  │                  (DC bias blocked)
            │                                    ▼
            │                            ┌──────────────┐
            │                            │  CR-11X CSP  │  charge-sensitive preamp
            │                            │  (U_CSP)     │  ±Vs, GND, decoupling
            │                            └──────┬───────┘
            │                                   ▼
            │                            ┌──────────────┐
            │                            │  CR-200-X    │  Gaussian shaper
            │                            │  (U_SHAPER)  │  P/Z trim (RV), ±Vs, GND
            │                            └──────┬───────┘
            │                          ░░ CR-210 (optional) ░░
            │                  ┌──────────────┐      ┌─ JP_BLR (0R bypass) ─┐
            │                  │  CR-210 BLR  │      │                      │
            │       shaper out ●──┤ (U_BLR)   ├──●───┴──────────────────────┴──● buffer in
            │                  └──────────────┘   (exactly one path populated)
            │                                          │
            │                                   ┌──────▼───────┐
            │                                   │  TI THS3491  │  output buffer (CFA)
            │                                   │  (U_BUF)     │  DNP by default; 0R-bypassed
            │                                   └──────┬───────┘
            │                                          │
            │                                        [ 49.9R ]  series source termination
            │                                          │
            │                                          ●  OUT   (50 Ω coax)
           GND, +VDC, -VDC distributed to every module
```

---

## Sub-blocks

### 1. Bias front-end (NEW)

Values below are designed for the Hamamatsu VUV4 in [circuit-design.md](circuit-design.md).

| Ref | Value | 0805? | Notes |
|---|---|---|---|
| `Rf1`, `Rf2` | **10 kΩ** each | yes | "R" of the RC+R filter; `Rf2` isolates the SiPM node so the fast charge flows to `Cc` (cold-only boards may raise to 100 kΩ–1 MΩ) |
| `Cf` | **100 nF, 100 V, X7R** | yes | "C" of the RC; `fc≈159 Hz` with `Rf1`; supply-noise bypass |
| `JP_Rf1`, `JP_Rf2` | 0R | yes | bypass links across `Rf1`/`Rf2` |
| `Cc` | **0.22 µF, 100 V, X7R** (KEMET C0805C224K1RACTU) | yes (HV part) | blocks DC bias; ≫ `Cdet`(1.28 nF) → ~99 % charge into CSP |

- **`BIAS_IN → Rf1 → (Cf to GND) → Rf2 → front-end node`** is the RC-in-series-with-R
  filter. Corner frequency ≈ `1 / (2π·Rf·Cf)`; choose `Rf`,`Cf` for the detector's bias
  current and the noise you need to reject. The series R also limits surge into a SiPM.
- **Front-end node → `SIPM`: solid copper (DC).** The detector is reverse-biased by the
  filtered DC. No series part here.
- **Front-end node → `Cc` → CSP input: AC.** `Cc` is the only thing between the HV node
  and the (ground-referenced) preamp input — it must hold off the full bias voltage.
- **Bypass:** fit `JP_Rf1`/`JP_Rf2` and DNP `Rf1`/`Rf2`/`Cf` to feed `BIAS_IN` straight
  to the node (see [bom.md](bom.md) DNP table).

> **Polarity (decided):** front-end node = SiPM **cathode**, biased **+45…+55 V**; anode →
> GND; read the cathode through `Cc`. Uses a positive bias supply. The CR-112 output-step
> sign is fixed by this and is a bench-confirm item — see
> [circuit-design.md](circuit-design.md#front-end-polarity-decision).

### 2. Charge-sensitive preamp — Cremat CR-11X (`U_CSP`)

- 8-pin SIP module. This build uses **CR-112** (13 mV/pC; D4) — suited to the VUV4's large
  per-p.e. charge; the reference board used CR-113. The CR-11X family is pin-compatible, so
  CR-113 is a drop-in if larger signals saturate the CR-112 (see [circuit-design.md](circuit-design.md)).
- Pinout (from the reference symbol `CR-11X`): `1=input`, `2=GND`, `3=NC`, `4=GND`,
  `5=-Vs`, `6=+Vs`, `7=GND`, `8=output`.
- Local decoupling on `+Vs`/`-Vs` (the reference uses values like 0.1 µF / 1 µF / 10 µF
  per rail — keep equivalents in 0805).
- **Socketed, not soldered:** all three Cremat modules (`U_CSP`,`U_SHAPER`,`U_BLR`) plug into
  **SIP-8 sockets** — Samtec **SS-108-TT-2** (`PinSocket_1x08_P2.54mm_Vertical`; alt Harwin
  D01-9970842), **36/board** (3 × 12). The modules are never soldered to the PCB.

### 3. Shaping amplifier — Cremat CR-200-X (`U_SHAPER`)

- 8-pin SIP module. The `-X` suffix selects shaping time (0.1–8 µs); choose per
  application. Pinout (reference symbol `CR-200`): `1=input`, `2=P/Z`, `3=GND`, `4=-Vs`,
  `5=+Vs`, `6=GND`, `7=GND`, `8=output`.
- **Pole-zero (P/Z) trim** on pin 2 via a trimpot (**Bourns 3296W 200 kΩ**, 25-turn;
  `RV_PZ`) — one per channel (**12/board**).

### 4. Baseline restorer — Cremat CR-210 (`U_BLR`) — NEW, optional

- 8-pin SIP module, follows the shaper. Holds the output baseline at ground at high
  count rate. Shares `+VDC`/`-VDC`/`GND` + decoupling.
- **Pinout — confirmed from `reference/cremat-CR-160-R7`** (via *its* `8pinSIP` footprint;
  on this board the CR-210 plugs into a SIP-8 socket, see block 2): same as the CR-200 except
  **pin 2 = GND** (CR-200 pin 2 is P/Z). Full map:
  `1=input, 2=GND, 3=GND, 4=-Vs, 5=+Vs, 6=GND, 7=GND, 8=output`.
- **Optional via bypass jumper, exactly as on the CR-160-R7** (its `JU1`): `JP_BLR` (0805
  0R) bridges the **CR-210 input node (shaper output) to the CR-210 output node**.
  - **Fitted:** populate `U_BLR`, leave `JP_BLR` open/DNP.
  - **Bypassed:** DNP `U_BLR`, close `JP_BLR` (0R) → shaper passes straight to the buffer.
  - See [modifications.md](../modifications.md#change-3) and the DNP table in [bom.md](bom.md).

### 5. Output buffer — TI THS3491 (`U_BUF`) — populate option, DNP by default

- The output buffer is a **TI THS3491** current-feedback line driver (8-pin SOIC/PowerPAD;
  DK `296-49085-1-ND`), with a **`49.9R` series** resistor for source termination into 50 Ω
  coax. It is **not** the EL5163/EL5167/LM7321 the reference used (that part could not run on
  the ±12 V rails and was replaced).
- **DNP by default:** `U_BUF` is a *per-channel populate option*. In the default build it is
  left unpopulated and a **0R jumper bypasses it**, so the shaper (via the CR-210) drives the
  `49.9R` back-termination directly. Populate `U_BUF` (and open the bypass) only when the
  extra line-drive is needed. There are **no buffer gain/offset trimpots** — the EL5167-era
  trims are gone.

---

## Per-channel I/O and nets

| Net / port | Direction | Connector | Description |
|---|---|---|---|
| `BIAS_IN` | in (per ch) | MCX `CONMCX013` | This channel's HV detector bias (≤ 70 V); own jack, not a shared rail |
| `SIPM` | out (per ch) | MCX `CONMCX013` | Coax to the detector; carries DC bias + the detector's pulse |
| `TEST` | in/out (per ch) | MCX `CONMCX013` | Per-channel test-pulse injection / monitor point |
| `OUT_50` | out (per ch) | MCX `CONMCX013` | 50 Ω-driven shaped pulse to DAQ |
| `+VDC`,`-VDC`,`GND` | power | (board power conn.) | Analog supply, **shared** across all modules |

---

## Optional-block jumper summary (per channel)

| Optional block | Populate for "fitted" | Populate for "bypassed" |
|---|---|---|
| Bias filter | `Rf1`,`Rf2`,`Cf` | `JP_Rf1`,`JP_Rf2` (0R); DNP `Rf1`,`Rf2`,`Cf` |
| CR-210 BLR | `U_BLR` (+ decoupling) | `JP_BLR` (0R); DNP `U_BLR` |
| THS3491 buffer | `U_BUF` (+ feedback) | 0R bypass link; DNP `U_BUF` — **default build** |

`Cc`, the CSP, and the shaper are **always populated** — they are the core amplifier. The
bias filter, the CR-210 BLR, and the **THS3491 output buffer** (DNP by default) are the
optional / populate blocks.

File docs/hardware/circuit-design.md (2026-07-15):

# Circuit & Front-End Design (Track 2)

Concrete component values and the front-end topology choices, derived for the target
detector. This is the Track 2 deliverable; it fixes the placeholder values used elsewhere
in the docs. Bench-verify items are listed at the end.

---

## Target detector — Hamamatsu VUV4 MPPC (S13370, 6 mm, 75 µm pixel)

| Parameter | Value | Source |
|---|---|---|
| Active area / pitch | 6 × 6 mm, 75 µm micro-cells | Hamamatsu (the "70 µm" pixel) |
| Terminal capacitance `Cdet` | **≈ 1.28 nF** | Hamamatsu / nEXO characterization |
| Breakdown `Vbr` | ≈ 55 V (room) / ≈ 42 V (86 K) | Hamamatsu |
| Operating reverse bias | **45–55 V** (≤ 70 V design ceiling, 100 V parts) | user |
| Charge / avalanche | **≈ 220 fC per 1 V overvoltage** (≈ 1.37×10⁶ e⁻/V) | user; matches Hamamatsu gain 5.8×10⁶ @ 4 V OV |
| Polarity | reverse-biased (cathode positive) | user |

The 45–55 V operating point sits just above the **cold** breakdown (~42–45 V at LXe
temperatures), i.e. the device is expected to run **cold** → **low dark current**, which
relaxes the bias-filter DC-drop budget (see below). The board must still behave at room
temperature for bench bring-up, where dark current is much higher.

---

## Operating point / charge budget

- Charge per fired micro-cell scales with overvoltage: `Q1pe ≈ 220 fC × OV[V]`.
  - At 1 V OV: 0.22 pC. At a typical 3–4 V OV: **0.66–0.88 pC** per p.e.
- The SiPM's own gain (~1.4×10⁶ e⁻ per p.e. per volt OV) is enormous, so **preamp noise
  is negligible for single-p.e. resolution** even with the large `Cdet` (the CSP ENC of a
  few 10³ e⁻ is ≪ the 10⁶ e⁻ single-p.e. charge).

---

## Front-end polarity (decision)

The channel topology biases and reads the **same** SiPM terminal (the front-end node),
with the other terminal grounded. To reverse-bias the VUV4 (cathode positive):

- **Front-end node = SiPM cathode**, biased to **+45…+55 V** through the filter.
- **SiPM anode → GND.**
- Read the cathode node through `Cc` into the CR-112.

This uses a **positive** bias supply (simplest). The avalanche discharges the node, so the
charge coupled into the CR-112 is negative-going; the resulting CR-112 output-step polarity
is fixed by this connection — **confirm the sign against the CR-112 datasheet on the bench**
and set the CR-200 / DAQ to match. (If the opposite polarity were ever required, the only
alternative in this single-node topology is anode-on-node with a **negative** bias supply;
not preferred.)

---

## Bias filter (the "RC-in-series-with-R", optional/bypassable)

```
 BIAS_IN(+45..55V) ──[ Rf1 ]──┬──[ Rf2 ]──► front-end node ──► SiPM cathode
                              │                            └──► Cc ─► CR-112
                             Cf
                              │
                             GND
```

| Part | Value | Footprint | Role |
|---|---|---|---|
| `Rf1` | **10 kΩ** | 0805 | series R of the RC low-pass (with `Cf`) |
| `Cf`  | **100 nF, 100 V, X7R** | 0805 | shunt reservoir / supply-noise bypass |
| `Rf2` | **10 kΩ** | 0805 | isolates the SiPM node from `Cf` so the fast charge flows into `Cc`, not back to the supply |

- **Supply-noise low-pass:** `fc = 1/(2π·Rf1·Cf) ≈ 159 Hz` → strong rejection of bias-supply
  ripple/noise above ~160 Hz.
- **DC drop** = `I_bias × (Rf1+Rf2) = I_bias × 20 kΩ`. Cold (`I` ~ nA): **negligible**
  (< 1 mV). Warm bench (`I` up to ~10 µA for a 6 mm VUV4): ~0.2 V — keep in mind when
  setting OV on the bench, or temporarily fit smaller `Rf` for warm characterization.
- **Node recovery** `Rf2·Cdet = 10 kΩ × 1.28 nF ≈ 13 µs` — fast enough for 1 µs shaping at
  moderate rates.
- **Tuning:** for production **cold-only** boards, `Rf1`/`Rf2` may be raised to **100 kΩ–1 MΩ**
  for stronger filtering and near-total charge transfer into the CSP, since the cold DC drop
  stays small. Keep 10 kΩ as the default that also survives warm bench testing.
- **Bypass (0R):** fit `JP_Rf1`,`JP_Rf2` and DNP `Rf1`,`Rf2`,`Cf` to feed `BIAS_IN` straight
  to the node (clean external supply / external filter).

---

## AC coupling `Cc`

| Part | Value | Footprint |
|---|---|---|
| `Cc` | **0.22 µF, 100 V, X7R** (KEMET C0805C224K1RACTU) | 0805 |

- Blocks the ≤ 55 V DC bias from the CR-112 input; 100 V rating gives margin (the reference
  board used `0.22 µF 100 V X5R`; this board uses the same value in **X7R**).
- **Charge transfer:** `Cc (0.22 µF) ≫ Cdet (1.28 nF)` by ~170×, so ≈ **99.4 %** of the
  SiPM charge transfers into the (virtual-ground) CR-112 input. This is why `Cc` is large —
  a small coupling cap comparable to `Cdet` would lose a large fraction of the signal.

---

## Preamp / shaper / output (carried from the reference, sized to the VUV4)

- **CR-112 CSP** (gain **13 mV/pC**): single-p.e. output step ≈ `0.22 pC × OV × 13 mV/pC`
  → **~10 mV at 3.5 V OV**, scaling linearly with p.e. count and OV.
  - **Linear range:** with a CSP output swing of ~±2 V, the CR-112 stays linear to
    ~`2 V / 13 mV·pC⁻¹ ≈ 150 pC` (≈ **200 p.e. at 3.5 V OV**). For larger scintillation
    signals, **CR-113** (10× lower gain, pin-compatible) is the drop-in fallback — but D4
    selected CR-112; revisit only if saturation is observed.
- **CR-200-1µs shaper** + pole-zero trim: as on the reference board; 1 µs shaping (D4).
- **Output buffer** (**TI THS3491** CFA, **DNP by default** — 0R-bypassed so the shaper drives
  the termination directly) + **49.9 Ω** series source termination into 50 Ω coax. No buffer
  gain/offset trims (the EL5167-era trims are gone).

---

## Power / decoupling

- Rails `+VDC` / `-VDC` (±Vs, Cremat-style, typ. ±12 V — confirm against module max ratings),
  shared across all 12 channels.
- Local decoupling at every Cremat module + op-amp (0.1 µF / 1 µF / 10 µF per the reference),
  0805 where the rating allows; bulk 10 µF + 100 µF per rail at entry.

---

## Bench-verify checklist (closes the remaining open items)

1. **CR-112 output-step polarity** for the cathode-on-node connection → set CR-200 / DAQ
   polarity to match.
2. **Warm vs cold OV offset** from the 20 kΩ bias-filter drop at the actual dark current;
   decide whether production cold boards raise `Rf` to 100 kΩ–1 MΩ.
3. **Single-p.e. amplitude & linear range** at the intended OV; confirm CR-112 (vs CR-113)
   is the right gain for the expected photon yield.
4. **Pole-zero trim** for a clean return-to-baseline at 1 µs shaping.

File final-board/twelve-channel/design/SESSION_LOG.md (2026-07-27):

# SESSION LOG — twelve-channel design

## 2026-07-08 — rebuild from the reworked single channel (schematic + PCB)

The pre-existing `final-board/twelve-channel` was built on the OLD single channel (no rail
protection, populated buffer, 235×264 mm, flat `_chNN` net labels). Deleted the old `design/`
+ `models-bom/` (preserved `sim/`) and rebuilt from the current single channel.

**Scout.** Mapped the single-channel cell (roles/refs/nets, common vs per-channel), the old
12-ch schematic + tile-and-replicate technique, and the current routed PCB structure.

**Schematic → hierarchical (ERC 0).** Split the single-channel `layout()` into
`layout_channel()` + `layout_power()` (verified byte-identical output). New `gen_sch.py`:
- CHILD `channel.kicad_sch` = the single channel minus board-level roles (J_PWR, F_P/D_RP/F_N/
  D_RN, C_BULKP/C_BULKN). Each symbol placed once with a **12-instance** block (strided refs),
  so KiCad expands to 12 channels. Self-contained (MCX inside, only +VDC/-VDC/GND global) →
  no hierarchical pins, matching `reference/cremat-x6-board`. Validated the KiCad-10 sheet +
  multi-instance format with a 2-instance spike first.
- ROOT `twelve-channel.kicad_sch` = 12 `(sheet)` instances + common power: `J_PWR` in +
  `J_DAISY` board-to-board daisy (raw rails), up-rated PTC/SS24 reverse-block, 470 µF bulk.
- `.kicad_pro` net-class patterns globbed for the `/chNN/` names.
- Netlist: 464 unique parts (R216 U48 C134 J50 RV12 D2 F2), 12 scoped channel net-groups.

**PCB → tile-and-replicate (DRC 0/0/0).** `gen_pcb.py`:
- Cloned the routed single-channel channel row ×12 (`Duplicate` every footprint/track/via,
  `Move` 25 mm/row, ref via role ch1→chNN, net `/X`→`/chNN/X`; pad nets + values + FPID + BOM
  fields pulled from `twelve-channel.net`). Channel-vs-COM tracks split by Y (clean, 0 straddle).
- Common section placed + hand-routed once: PTC/Schottky oriented so each `_F` pad pair is at
  the same y; `+VDC_IN` on a bus above / `-VDC_IN` below (stubs off the outer pins never cross
  the mid GND pin); SMD bulk rail pads take plane vias. Board-wide plane pours carry the rails.
- Iterated DRC: fixed bulk-cap opens (SMD → plane vias), common-section shorts/mask-bridges
  (bus routing), mounting-hole collisions with edge MCX (moved to top/bottom strips + bottom
  margin), and common-part parity (value/FPID/fields from netlist). `fill_zones.py` +
  `polish_silk.py` (refdes → F.Fab) → **0 violations / 0 unconnected / 0 schematic-parity**.

Result: 138 × 335 mm, 468 footprints, 1836 tracks + 424 vias, 120 DNP. Render:
`twelve-channel-top.png`.

**Open:** regenerate the BOM (models-bom); verify the provisional up-rated protection MPNs.

---

## 2026-07-11 — NEXT UP (resume here): propagate single-channel connector fixes to 12-ch

**This board is STALE.** It was tiled from the single channel BEFORE the 2026-07-11 connector
fixes. It still uses the OLD MCX footprint — `cremat:MCX_CONMCX013_EdgeMount` (4 child-sheet
refs, **48** board instances) with old `CONMCX013.STEP` in `design/lib/cremat.pretty/` — and
the old J5 orientation. The single channel (`integration/single-channel/design`, session 8)
now has: (a) the user's **Linx `cremat:MCX_CONMCX013-T`** footprint, (b) MCX 3D
`(rotate (xyz 270 0 0))` so the coax faces off the edge, (c) MCX edge-**notch** outline, and
(d) J5 screw terminal at **rot 180**.

**How to propagate.** The 12-ch `gen_pcb.py` **tiles by cloning the routed single-channel row**
(`integration/single-channel/design/channel.kicad_pcb`) ×12, and `gen_sch.py` instantiates the
child sheet 12×. Since the single-channel source is already updated, the cleanest path is to
**re-run the 12-ch generators against it** and then verify each item transferred:

1. **Footprint files.** Copy `MCX_CONMCX013-T.kicad_mod` + `CONMCX013-T.step` into the 12-ch
   `design/lib/cremat.pretty/`. (The `.kicad_mod` already has pads 1 / `2`×2 and the `rotate
   270` 3D fix baked in.)
2. **Schematic.** Re-run 12-ch `gen_sch.py` (its `FP_MCX` must point at `cremat:MCX_CONMCX013-T`;
   grep the child `channel.kicad_sch` afterward — must show 0 refs to `_EdgeMount`). ERC 0.
3. **PCB.** Re-run 12-ch `gen_pcb.py` (re-tiles the updated single channel). Then confirm on the
   regenerated board:
   - all **48** MCX FPIDs = `cremat:MCX_CONMCX013-T`, model `(rotate (xyz 270 0 0))`;
   - the **notched outline** ports for 48 MCX = **24 notches per long edge** (single-channel
     `gen_pcb.py` cuts the notch read-back from each placed MCX + demotes footprint Edge.Cuts →
     Dwgs.User — make sure the 12-ch outline builder does the same for every tiled MCX);
   - a `channel.kicad_dru`/board `.kicad_dru` waives `edge_clearance` for
     `A.Library_Link == 'cremat:MCX_CONMCX013-T'`;
   - J5-equivalent power connector(s) at rot 180 (wire entry to the rear/top edge).
4. **Fill zones, DRC → 0/0, render** to eyeball that all 48 MCX lie flat facing off the edges
   and J5 faces out. Delete the old `MCX_CONMCX013_EdgeMount.kicad_mod` + `CONMCX013.STEP` from
   the 12-ch lib once nothing references them.

**Cross-refs:** exact recipe + the KIPRJMOD/quality **render gotcha** →
`integration/single-channel/design/SESSION_LOG.md` (2026-07-11); autoroute (Java 25 +
dead-proxy headless) → `docs/FREEROUTING.md` — **both tools must be reinstalled on the new
machine** (`C:\Users\<you>\tools\jdk-25...jre` + `freerouting-2.2.4.jar`). The single-channel
`channel.kicad_pcb` is the proven reference: routed, DRC 0/0.

NOTE: this board's `channel.kicad_sch` / `twelve-channel.kicad_sch` / `.kicad_pro` had a large
uncommitted rebuild (from 2026-07-08) — now committed WIP; open it and confirm it's clean
before starting layout.

---

## 2026-07-11 — session 9 — connector fixes PROPAGATED to 12-ch (DONE)

Followed the recipe above; all items transferred + verified:
- Copied `MCX_CONMCX013-T.kicad_mod` + `CONMCX013-T.step` into the 12-ch lib; **deleted** the old
  `MCX_CONMCX013_EdgeMount.kicad_mod` + generated `CONMCX013.step` + the now-obsolete `gen_mcx_step.py`.
- `gen_sch.py` re-run (inherits `sc.FP_MCX = cremat:MCX_CONMCX013-T`): child `channel.kicad_sch`
  now **0** refs to `_EdgeMount`, 4 to `-T`. ERC 0.
- `gen_pcb.py` updated: (a) **stop** promoting MCX cutouts to Edge.Cuts; (b) **notch builder** reads
  each tiled MCX's Dwgs.User cutout and cuts **48 notches (24/edge)** into the outline; (c) `.kicad_dru`
  waives `edge_clearance` for `cremat:MCX_CONMCX013-T`; (d) `J_PWR`/`J_DAISY` rot **180** (funnels out).
  Also add MPN/Mfr/DistPN fields to the tiled channel footprints (the regenerated single-channel board
  drops them → had been 199 `field_mismatch`).
- Verified on the board: 48 MCX = `cremat:MCX_CONMCX013-T`, model rot **(270,0,0)**; J49/J50 rot 180;
  48 notches; 0 old `_EdgeMount`. **DRC (error severity) 0 / 0 / 0**; the 48 `lib_footprint_mismatch`
  are warning-level + intentional (Edge.Cuts → Dwgs.User demotion). Render (`twelve-channel-3d.png`,
  from the design dir, `--quality high`) confirms the MCX lie flat facing off the edges. Fab regenerated
  (`fab/`, git-ignored).

Board 138 × 334.7 mm, DRC 0/0/0. **Order-ready pending the enclosure-depth width resize** (widen the
138 mm dimension so the MCX edges meet the box front/back bulkheads).

---

## 2026-07-11 — session 10 — widened to the Hammond RM2U1908 enclosure (DONE)

The user picked a **Hammond RM2U1908** 2U rack case (8"/203 mm external, ~185 mm internal depth) to
stack two 12-ch boards. The board must be as **wide as the box is deep** so the two MCX rows land on
the front and back bulkheads. Widened the board **138 → 180 mm** (one parameter, `gen_pcb.py` `W`,
conservatively 5 mm shy of the ~185 mm internal — the barrels reach through the panel; **adjust to
the box's real internal depth**).

- The single-channel **tile stays 138 mm** (`W_CELL`); the board grows only on the **output/bias
  (right) side** by `DW = W - W_CELL = 42 mm`. Signal integrity is unaffected — the shaper outputs
  are slow (µs) Gaussian pulses, so the longer OUT_50/BIAS run is immaterial; BIAS is DC.
- Clone loop: for each right-edge MCX (`RIGHT_MCX = {J_OUT50, J_BIAS}`) record pad-1, `Move(+DW)`,
  and lay a 0.4 mm **F.Cu extension** from the old pad location to the new one so the moved jack stays
  connected (this is why unconnected stays 0). The notch reader then sees the MCX at `x≈W` and cuts
  the right-edge notch there; left-edge (input) MCX are untouched.
- Re-ran `gen_pcb.py` + `fill_zones.py` + `polish_silk.py`: **180.0 × 334.7 mm, 48 notches (24 L /
  24 R), DRC 0 / 0 / 0** (incl. 0 unconnected). Render `twelve-channel-3d.png` confirms the output
  MCX sit on the far edge with the extension traces crossing the right region; input side stays
  compact. Fab regenerated at 180 mm (`fab/`, git-ignored).

**Order-ready.** Remaining pre-order check is purely mechanical: confirm `W=180` against the actual
RM2U1908 internal depth before sending gerbers.

---
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

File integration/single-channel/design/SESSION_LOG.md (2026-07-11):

# Session Log — B1 chan-design

> **Ground truth, append-only.** One dated entry per working session: what you did, exact
> commands/tools, results (numbers, ERC/DRC counts, sim figures of merit), decisions **and
> why**, dead-ends, next steps. Never rewrite earlier entries.

Track: `B1 chan-design` · Sub-component: `single-channel` (Phase B) · Aspect: `design`
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

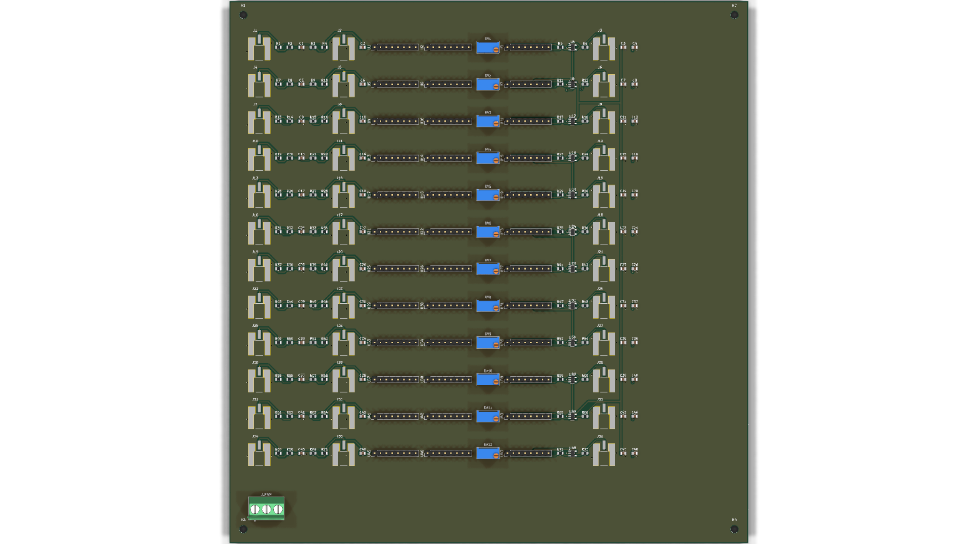
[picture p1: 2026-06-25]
hardware/routed-top.png

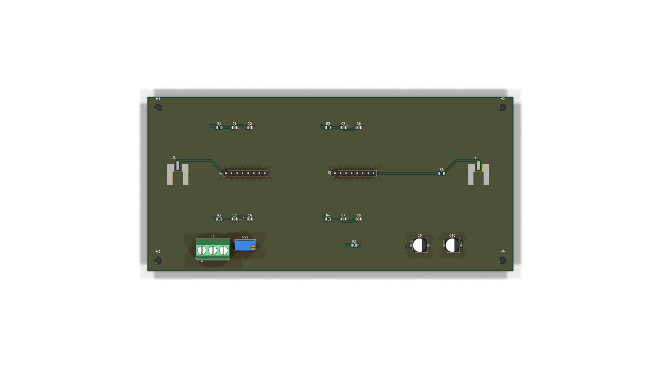
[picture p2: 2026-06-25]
chips-board/shaper-cr200-cr210/design/plots/shaper_M2_top.png

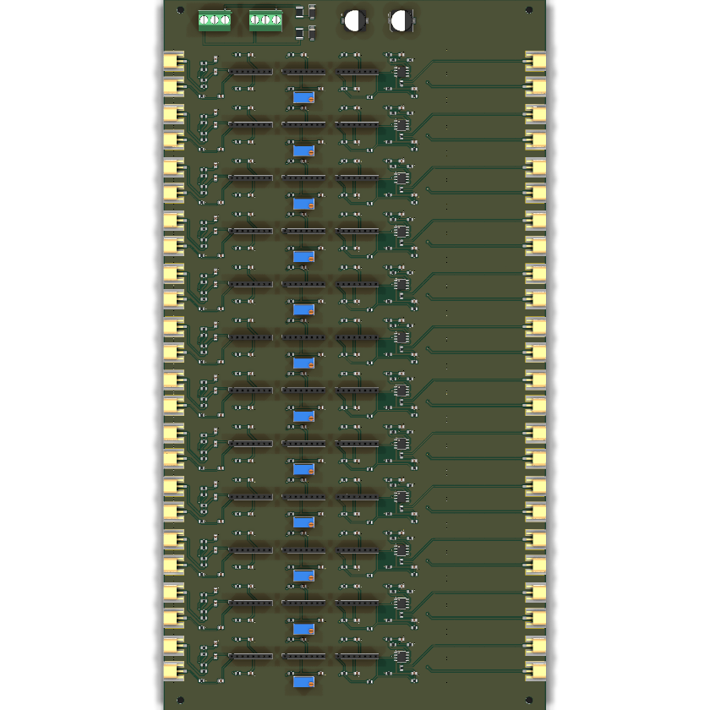
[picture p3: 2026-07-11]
final-board/twelve-channel/design/twelve-channel-top.png

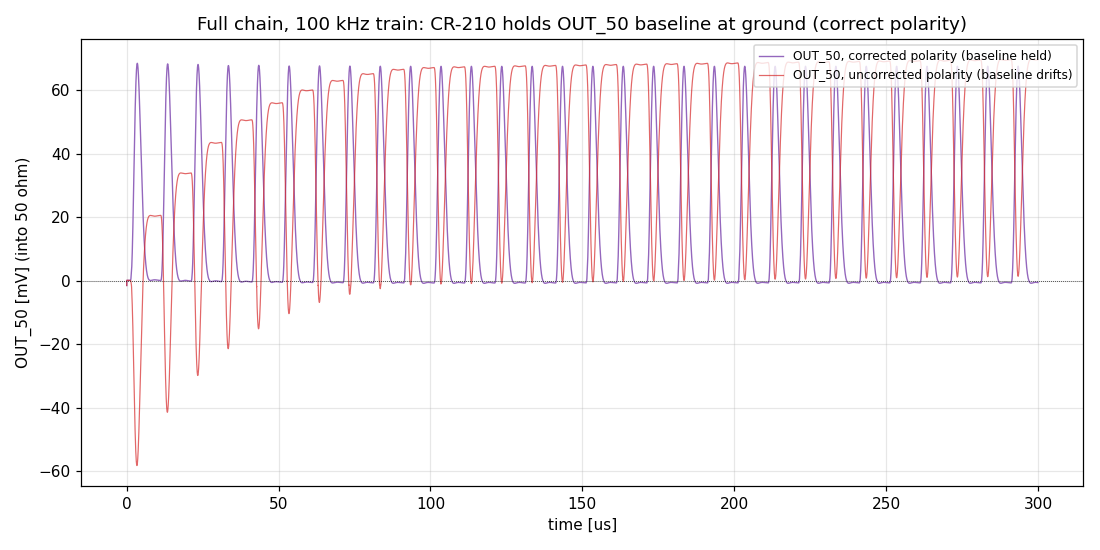
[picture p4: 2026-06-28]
integration/single-channel/sim/plots/chain_train_baseline.png

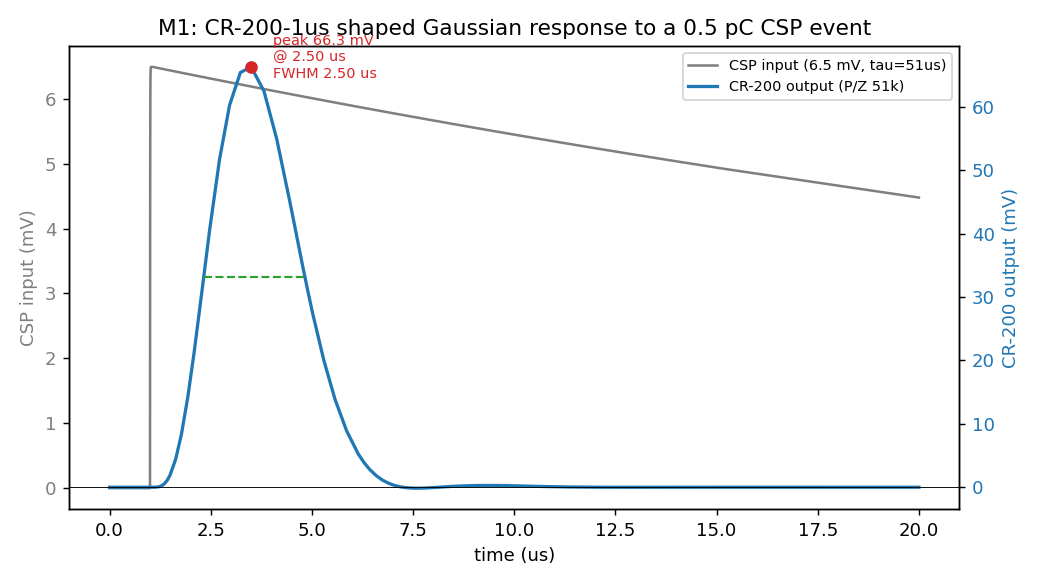
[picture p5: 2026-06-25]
chips-board/shaper-cr200-cr210/sim/plots/m1_cr200_gaussian.png

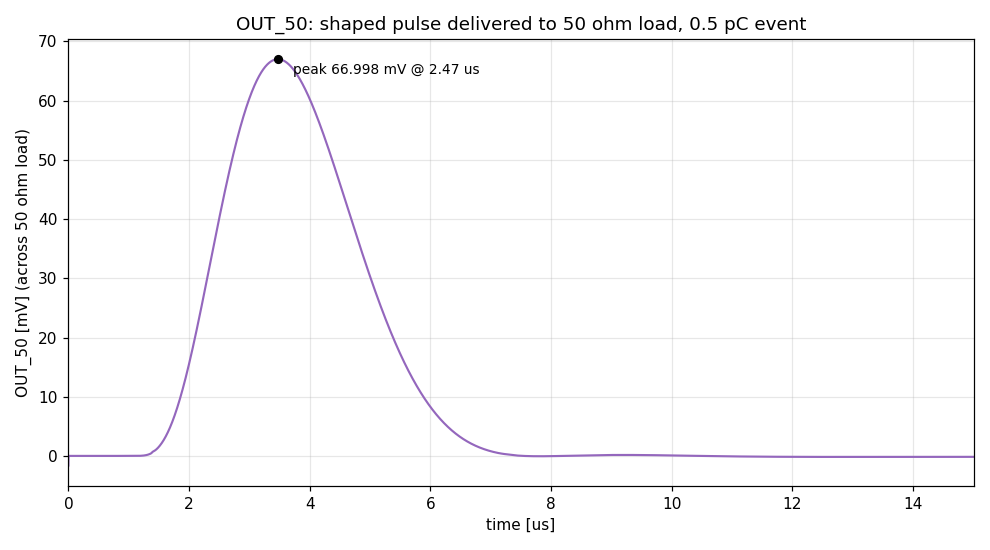
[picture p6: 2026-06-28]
final-board/twelve-channel/sim/plots/chain_out50_detail.png

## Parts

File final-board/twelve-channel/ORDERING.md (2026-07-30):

# ORDERING — 12-channel board via JLCPCB (fab + SMT/THT assembly) + DigiKey (hand parts)

> Master buy-sheet. Two orders: **JLCPCB** (boards + all SMD parts **and** the THT trimpots +
> screw terminals assembled — MCX included) and **DigiKey** (SIP-8 sockets + case, hand parts).
> The Cremat modules you already have plug into the sockets. Part numbers/stock/prices were
> live-verified 2026-07-11 → 2026-07-30. Re-check stock in the JLC BOM tool at order time.

**BUILD PLAN: 5 assembled boards.** JLC: **fab qty 5** (JLC's 4-layer minimum) + **assembly qty 5**
(all five assembled — no bare spares; raise PCB qty if you want some). DigiKey hand parts: **SIP-8
sockets for 2.5 boards** (the 2 boxed boards + spares) and **one 2U case** (holds the 2-board stack; the
other 3 boards are spares, unboxed).

> ## ⚠ Assembly tier: **STANDARD, not Economic**
> The MCX edge jack **BWMCX-KEF (LCSC C5250059)** is the only true-MCX part in JLC's library;
> it is **PCBA type "Standard Only"** (verified on jlcpcb.com/partdetail 2026-07-30) with
> **"High" assembly difficulty**. It is **not** in the Economic-tier feeder library, so an
> Economic-tier order rejects all 48 MCX as **UNMATCHED at upload** — the same failure mode
> the ROQANG 470 µF hit. **Select JLC's Standard assembly tier.** Standard places every part
> (Basic, Extended, Standard-only) plus the THT parts (wave soldering) and covers this 4-layer
> board. The Economic fee figures no longer apply — **the live Standard-tier quote after BOM/CPL
> upload is authoritative.** (The only Economic-tier edge jack, BWMMCX-KEF-B / C47324993, is
> **MMCX** — a smaller, incompatible family — so it is not an option.)

## The split

| Who | What | Files |
|---|---|---|
| **JLCPCB** | 4-layer PCB fab + **Standard**-tier assembly of all **308** parts/board: **294 SMD** (246 passives/diodes/PTC + 48 MCX edge jacks) + **14 THT wave-soldered** (12 trimpots + 2 screw terminals) | `design/fab/jlc/` (gerber zip, BOM, CPL) |
| **DigiKey** | Hand parts: **36× SIP-8 sockets** per board + **1× 2U case** (+ optional buffer parts, DNP) | `models-bom/digikey-hand-bom.csv` |
| **You already have** | Cremat CR-112 / CR-200-1us / CR-210 ×12 per board (×5 boards = 60 each) — plug into sockets | — |

Hand-solder is now **only the SIP-8 sockets** (you wanted to solder those anyway; no turned-pin
8P SIP socket is both in JLC's library and in stock — see the socket note). Everything else —
SMD, the 48 MCX, the 12 trimpots, and the 2 screw terminals — lands assembled by JLC.

## 1. JLCPCB order (jlcpcb.com → "Order now" wizard)

**Files (in `design/fab/jlc/`):**
1. `gerber-twelve-channel-jlc.zip` — upload first (gerbers + Excellon drill; KiCad 10 export).
   *Regenerated 2026-07-30 to add the D1/D2 silk cathode stripes (top silk only; copper/drill
   unchanged). The zip is gitignored — regenerate from `twelve-channel.kicad_pcb` if missing
   (`kicad-cli pcb export gerbers|drill` → zip, see REVIEW.md).*
2. `bom-twelve-channel-jlc.csv` — BOM, JLC headers (`Comment,Designator,Footprint,JLCPCB Part #`).
   **15 lines**: MCX (`BWMCX-KEF … C5250059`, J1–J48), trimpot (`3296W-1-204 … C48997932`, RV1–RV12),
   screw terminal (`KF128-5.0-3P … C474951`, J49–J50) — the last two THT, wave-soldered.
3. `cpl-twelve-channel-jlc.csv` — pick-and-place, JLC headers (`Designator,Mid X,Mid Y,Layer,Rotation`),
   **308 placements** = 294 SMD (incl. 48 MCX) + 14 THT (12 trimpots + 2 terminals). Only the 36
   SIP-8 sockets and all DNP are excluded. *(Carries manual CPL corrections — see the ⚠ list below.)*

**Wizard settings (verified against a live quote, qty 5):**
- Detected size 213.2 × 334.7 mm, **4 layers**, 1.6 mm, 1 oz outer / 0.5 oz inner, green.
- Surface finish: **leaded HASL** ($73.70/5 boards incl. $25 eng fee + $5 large-size) or
  **ENIG** (+$24.70 → $98.40/5). ENIG is nicer for the MCX edge pads; HASL is fine.
- **Impedance: leave OFF (normal build).** Do **not** request controlled impedance. If a
  remarks/note field is offered, paste (≤200 char, JLC's limit):
  > `4-layer, 1.6mm, JLC04161H-7628 stackup. No controlled impedance. Do not tune trace
  > width; signals are grounded-coplanar (GND pour + inner GND plane), not microstrip.` *(165 chars)*
- The board's 48 edge notches are routed slots ≥5 mm — well within capability; expect at
  most a manual engineering review, no surcharge (routing density ~12 m/m² vs 80 limit).
- **PCB Assembly: STANDARD tier (see ⚠ above), top side, PCBA qty = 5.** Set PCB qty 5, assembly
  qty 5 — all five assembled. Upload BOM + CPL when prompted.
- **Standard-tier fees (live quote is authoritative):** a Standard setup fee + stencil +
  per-Extended-part feeder fees + THT wave-solder charge + per-joint + parts. The MCX (C5250059)
  is **Extended + "High" difficulty**, so expect a **DFM review** and possibly a handling surcharge
  on the edge connector. Per-board parts ≈ 48× MCX @ $0.49 + 12× trimpot @ $0.23 + 2× terminal
  @ $0.39 + SMD passives (~$18) ≈ **$45/board**.
  ⚠ JLC also lists an undocumented per-order assembly "Large Size" fee (~$59) that may appear
  for a 334.7 mm board; the live quote is authoritative.

**In the parts-review screen, check (manual CPL corrections — all live ONLY in the CPL; re-apply
if the CPL is ever regenerated from the board):**
- **J1–J48 (MCX):** rotation +90° CCW (left 0° / right 180°) **and** `Mid X` −1.8 mm inboard
  (left 6.3→8.1, right 206.9→205.1) — the BWMCX-KEF mounting reference is offset from the Linx
  land. Regen → re-apply +90° (left −90°→0°, right +90°→180°) and −1.8 mm on Mid X. Confirm the
  barrel points off the board edge and the part seats on its pads.
- **D1/D2 (Schottky):** rotation +180° (→90°) so the cathode band lands on **pad 1** (cathode:
  D1=+VDC, D2=−VDC_F, per `D_Schottky` pin1=K). A **silk cathode stripe** was added at pad 1 on
  both (board + gerber regenerated). Regen → re-apply +180°. Confirm each band aligns with its stripe.
- **RV1–RV12 (trimpots):** rotation 90° CW (→270°) **and** `Mid X` −2.54 mm to the pin centroid
  (the 3296W footprint origin sits on pin 1, one pitch right of center). Regen → re-apply.
- **J49/J50 (terminals):** `Mid X` −5.0 mm to the pin centroid (the MKDS origin sits on pin 1,
  one 5 mm pitch right of center). Regen → re-apply. Confirm the wire openings face the board edge.
- **C133/C134 (electrolytic)** are already correct — leave them.
- The 470 µF stays **C494847** (Panasonic EEE-FN1V471UP); it is "Economic + Standard" PCBA and
  the verified choice. (The ROQANG C72519 substitute was Standard-only → UNMATCHED in Economic,
  but that's moot in the Standard tier we're ordering.)

**BOM parts encoded (subs chosen to hit JLC's Basic library / dodge per-line feeder fees):**

| Board value (silk/BOM) | Placed at JLC | LCSC | Class | Why |
|---|---|---|---|---|
| 49.9R Yageo | UNI-ROYAL 0805W8F499JT5E (1%) | C17720 | Basic | spec-identical |
| 0.22 µF 100 V KEMET | **exact KEMET** C0805C224K1RACTU | C2167405 | Ext | HV part — exact (fallback Yageo C513710) |
| 0R Yageo | UNI-ROYAL 0805W8F0000T5E | C17477 | Basic | 0R jumper |
| 100 nF 100 V Samsung | **exact** CL21B104KCFNNNE | C28233 | Basic | exact AND Basic |
| 10k Yageo | **YAGEO RC0805FR-0710KL** (1%) | C84376 | Basic | 1.03 M in stock 2026-07-28 |
| 10 µF 25 V KEMET | Samsung CL21A106KAYNNNE (25 V X5R) | C15850 | Basic | KEMET 25V not at LCSC in 0805 |
| 10 pF 1% C0G Yageo | **exact** CC0805FRNPO9BN100 | C541512 | Ext | precision test-input cap; no Basic option |
| 4.7R Yageo (5%) | **FOJAN FRC0805F4R70TS** (1%) | C2933459 | **Ext** | Basic C17675 went LCSC-OOS — see ⚠ below |
| 47R Yageo (5%) | UNI-ROYAL 0805W8F470KT5E equiv | C17714 | Basic | equal-or-better |
| 470 µF 35 V Panasonic | **exact** EEEFN1V471UP | C494847 | Ext | JLC "Economic+Standard" PCBA |
| PTC 1812 1.1 A Littelfuse | **exact** 1812L110/24DR | C207066 | Ext | no Basic PTC |
| SSA24 Schottky | **MDD SS34** (SMA, 40 V, 3 A) | C8678 | Basic | board silk SSA24 — electrically compatible |
| **MCX edge jack 50R** | **BAT WIRELESS BWMCX-KEF** | **C5250059** | **Ext** | SMD edge-mount, Standard-only + High difficulty; drop-in on the Linx CONMCX013 land. J1–J48. |
| **200k trimpot 3296W** | **JIERR 3296W-1-204** | **C48997932** | **Ext** | THT wave-solder; exact 3296W footprint + 200k. RV1–RV12. |
| **Screw terminal 3-pos** | **Cixi Kefa KF128-5.0-3P** | **C474951** | **Ext** | THT wave-solder; exact 5.00 mm 3-pos footprint. J49–J50. |

> **⚠ 4.7 Ω (R6…R209, 144 pcs).** The only JLC-Basic 4.7 Ω 0805 was C17675, now LCSC-OOS, so the
> BOM uses Extended C2933459 (feeder fee). **At upload, check whether JLC's assembly pool still
> lists C17675 as in-stock Basic** (its feeders are a separate pool from LCSC retail); if so revert
> to C17675 to drop the fee. Electrically identical.

DNP stays DNP (buffer block THS3491 + 976R + bypass-variant jumpers/caps are **not** in the
JLC BOM/CPL — populate by hand later if wanted).

## 2. DigiKey order (hand parts) — `models-bom/digikey-hand-bom.csv`

Quick-Add paste for the **5-board build** (sockets for 2.5 boards; one 2U case):

```
612-SS-108-TT-2-ND, 90
HM1166-ND, 1
```

= **~$304.03** (sockets 90 × $1.17 ≈ $105.30 + one 2U case $198.73). Optional buffer if ever
populating (5 boards, DNP by default): `296-49085-1-ND, 60` + `311-976CRCT-ND, 120` (+~$1.1k).
⚠ **Sockets: order qty 90 (2.5 boards' worth); DigiKey stock ~649.** The trimpots and screw
terminals are **no longer on this list** — JLC wave-solders them now.

## 3. Hand-assembly order of operations (per board — ×5)

1. JLC boards arrive with all SMD parts + the 48 MCX + 12 trimpots + 2 screw terminals mounted.
2. **Inspect the 48 MCX joints first** (edge-mount, "High" difficulty): barrel square over its
   edge slot, centre pin / ground pads wetted. Also check the diode bands align with the silk stripes.
3. Hand-solder the **36× SIP-8 sockets** (plug a Cremat module in while soldering so the 8 align).
4. Plug in the Cremat modules; set trimpots per the P/Z procedure (`sim/SESSION_REPORT.md`).
5. **Box mounting (2U):** mill the front/rear panel slots and mount the 2-board stack on standoffs
   in the 2U case — see the box-assembly drawings + standoff BOM (mechanical design).

## Cost snapshot (the 5-board build plan, indicative — live JLC quote authoritative)

| Item | Cost |
|---|---|
| JLC: 5× PCB fab (4L, HASL, large-size incl.) | ~$74 (+$25 ENIG option) |
| JLC: **Standard**-tier assembly, 5 boards (setup + stencil + feeders + THT wave + joints + parts) | ~$275 |
| DigiKey: 90× SIP-8 sockets + 1× 2U case + standoffs | ~$311 |
| **Total ex-shipping (Cremat modules already owned)** | **~$660** |

Shipping: JLC ~$40 (DHL, 5 boards); DigiKey usual. (+ possible ~$59 JLC assembly large-size fee,
and a DFM/handling surcharge for the High-difficulty MCX — see above.)

Full DigiKey-only reference (if ever skipping JLC assembly): `models-bom/PURCHASING.md`.

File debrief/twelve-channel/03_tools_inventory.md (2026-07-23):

# 03 — Tools inventory

All run under `C:\Program Files\KiCad\10.0\bin\python.exe`. All take **no CLI arguments** — paths
are module constants resolved relative to `HERE = os.path.dirname(os.path.abspath(__file__))`.
That is a real convention of this repo, discussed critically in `04_kernel.md`.

## Summary

| path | purpose | reuse | state |
|---|---|---|---|
| `integration/single-channel/design/gen_sch.py` (694 L) | Draw one channel + power entry as a real wired schematic; **also the shared drawing library** the 12-ch generator imports | `C:analog-signal-chain` | alive `[shared]` |
| `final-board/twelve-channel/design/gen_sch.py` (324 L) | 12-ch hierarchical schematic: 12 child sheets + root + `.kicad_pro` | `C:repeated-block` | alive |
| `final-board/twelve-channel/design/gen_pcb.py` (349 L) | Tile the routed cell ×12, place/route common section, outline+notches, zones, DRU | `C:repeated-block` | alive |
| `integration/single-channel/design/gen_pcb.py` (327 L) | Single-channel board generator | `C:analog-signal-chain` | alive `[other-session]` |
| `final-board/twelve-channel/design/fill_zones.py` (53 L) | Separate-process zone fill (+ netclass self-heal) | `G` | alive |
| `integration/single-channel/design/fill_zones.py` (44 L) | same, single-channel | `G` | alive `[shared]` |
| `final-board/twelve-channel/design/polish_silk.py` (24 L) | Move refdes silkscreen → F.Fab to clear silk-overlap warnings | `G` | alive |
| `final-board/twelve-channel/models-bom/gen_bom.py` (149 L) | Project BOM from the netlist, DNP-aware, qty-tiered pricing | `G` | alive |
| `final-board/twelve-channel/models-bom/gen_purchasing.py` (220 L) | Purchasing/sourcing doc: per-vendor line items, spares, enclosure | `C:ordering` | alive |
| `integration/single-channel/design/export_dsn.py` (19 L) | Board → Specctra `.dsn` for FreeRouting | `G` | alive `[other-session]` |
| `integration/single-channel/design/import_ses.py` (18 L) | FreeRouting `.ses` → board | `G` | alive `[other-session]` |
| `chips-board/*/gen_sch.py`, `hardware/gen_sch.py` | Phase-A sub-board generators (CSP, shaper) | `P` | superseded |
| — `gen_mcx_step.py` | generated an MCX 3D model | `P` | **dead** — deleted once the vendor's real STEP was obtained `[recalled]` |

Line counts `[verified-run]`. Below, only the tools I owned are detailed.

---

## `final-board/twelve-channel/design/gen_sch.py` — 12-ch hierarchical schematic

**Interface:** `PY gen_sch.py`, no args. Writes into its own directory.

**Inputs:** imports `integration/single-channel/design/gen_sch.py` as a module (via
`importlib.util.spec_from_file_location`) and **monkey-patches its emitter functions** to switch
from single-instance to per-channel output. Also reads
`integration/single-channel/design/channel.kicad_pro` as the template for the project file.

**Outputs:** `channel_ch01..ch12.kicad_sch`, `twelve-channel.kicad_sch`, `twelve-channel.kicad_pro`.

**Format/API touched:** writes `.kicad_sch` **as text** (no KiCad API for schematics — see
`05_domain_knowledge.md`), and `.kicad_pro` as JSON.

**Key internals worth carrying forward:**

- `BOARD_ROLES` — the roles that belong to the *root* (power entry) rather than a channel. The
  child is "the single channel minus these".
- `stride_ref(ref, n)` — turns ch1's `R6` into chN's `R{6 + (n-1)*18}`, using a per-prefix count
  computed once from the role list. Reference numbering must be *derived*, never hand-maintained.
- `CH[0]` — a module-level "current channel" the patched emitters read. Crude but effective.
- `remap_uuids(text, n)` — after generating a child's text, rewrite every `(uuid "...")` to a
  per-channel value via `uuid5`, while leaving `(path ...)` references untouched. This is what
  makes 12 structurally identical sheets have unique element identities.
- `build_pro()` — copies the single-channel `.kicad_pro`, then fixes: netclass patterns for
  hierarchical net names, `top_level_sheets` (else the GUI opens the *child*), the sheet list, and
  — critically — **fills the schematic fields on every netclass** (`06_gotchas.md` #1).

**Side effects / idempotency:** fully idempotent. Deterministic `uuid5` from a fixed namespace
means re-running produces byte-identical files. **This is a deliberate and load-bearing property**
— it makes "regenerate and diff" a safe, meaningful operation, and it lets `git status` answer
"did my change do anything unexpected?"

**Limitations:** the geometry of the channel is entirely inherited from the single-channel module;
this file only handles replication and the root. Sheet placement on the root (2 columns × 6 rows)
is hardcoded.

**To generalise:** parameterise `NCH`, the role split, and the sheet grid. The multi-instance ↔
per-file decision (below) should be a flag.

---

## `final-board/twelve-channel/design/gen_pcb.py` — tiling board generator

**Interface:** `PY gen_pcb.py`, no args.

**Inputs:** `integration/single-channel/design/channel.kicad_pcb` (routed cell),
`twelve-channel.net`. **Outputs:** `twelve-channel.kicad_pcb`, `twelve-channel.kicad_dru`.

**API touched:** `pcbnew` — `LoadBoard`, `Duplicate`, `Move`, `SetReference`, `SetPath`,
`SetNetCode`/`GetNetsByName`, `FootprintLoad`, zone + track + via construction, `Edge_Cuts`
shapes, `Save`.

**Notable internals:**

- `parse_netlist()` — regex parser producing `{ref: (fpid, sym_path, value, fields)}` and
  `{(ref,pad): net}`. **`sym_path` must be `sheetpath.tstamps + component.tstamps`** — building it
  from the component tstamp alone silently collapses all 12 instances onto one path
  (`06_gotchas.md` #2).
- `dup(item)` — `Duplicate(False)` with a `TypeError` fallback to `Duplicate()`, papering over an
  API signature difference.
- The channel/common split by Y coordinate, with an assertion that nothing straddles.
- Outline builder that reads each placed MCX's `Dwgs.User` notch and subtracts it from the
  rectangle.
- Emits a `.kicad_dru` rule waiving `edge_clearance` for the MCX library link.

**Side effects:** overwrites the board wholesale. **Not** safe to run against a board a human has
hand-edited — it regenerates from the cell. Idempotent given the same inputs.

**Limitations:** the common power section's placement and routing are hardcoded coordinates. Row
pitch, board width and the notch geometry are constants. Widening the board for the enclosure was
a one-parameter change (`W`), which was the payoff of generating rather than drawing.

---

## `fill_zones.py` — separate-process zone fill  `G`

Loads the saved board, `ZONE_FILLER(board).Fill(board.Zones())`, saves. Exists as a separate
process **because doing it in-process segfaults headlessly**.

The 12-ch copy also **self-heals the netclass patterns**: it checks that the `hv_bias` class is
still present/assigned and restores it with a warning if the GUI has flattened the `.kicad_pro`.
That defensive check exists because opening the project in the GUI could rewrite the project file
and silently drop netclass patterns. `[recalled]`

## `polish_silk.py`  `G`

Moves reference designators from `F.SilkS` to `F.Fab` to clear silk-overlap warnings on a dense
board. 24 lines. Cosmetic but it is the difference between a DRC report you read and one you
ignore.

## `models-bom/gen_bom.py`  `G`

Reads `twelve-channel.net`, groups by MPN, applies DNP rules, emits the project BOM with
`MPN`/`Manufacturer`/`Distributor PN` columns. Handles the **up-rated common parts** (the 12-ch
power entry uses higher-current PTCs/diodes/bulk caps than the single channel) by overriding
values per role, and appends non-schematic line items (the SIP-8 sockets — real BOM lines that
exist nowhere in the netlist, because the schematic has module symbols, not sockets).

**Generalisable lesson:** a BOM is *not* a projection of the netlist. It needs (a) DNP variants,
(b) parts that exist mechanically but not electrically, (c) quantity tiers, (d) spares.

## `models-bom/gen_purchasing.py`  `C:ordering`

Emits the purchasing document: per-vendor grouped line items, quantity = `ceil(per_board × boards
× 1.2)` for hand-soldered parts (spares) but exact for the enclosure, distributor part numbers,
prices, and the JLC/DigiKey split. Encodes which parts the assembler places vs which the human
solders.

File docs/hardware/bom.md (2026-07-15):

# Bill of Materials & Population Strategy

How the BOM is organized, the 0805 passive policy, the Cremat modules, and — most
importantly — the **DNP / populate tables** that define each build variant. The
authoritative, fielded BOM lives in the KiCad project once implemented; this document is
the policy + the optional-population logic.

Carry the reference board's BOM fields forward (`MPN`, `MFN`, `VPN`, `VN`, plus a `DNP`
flag), the same convention `ets-breakout` and the reference board use.

---

## Passive size policy (Change 2)

- **Default 0805** for every R and C that allows it.
- **0R bypass jumpers** are 0805 zero-ohm links (or solder-jumper footprints for the
  tightest spots).
- **Voltage-rated exceptions stay 0805 but with HV dielectric:** the AC-coupling cap `Cc`
  and the bias-filter `Cf`/`Rf*` see the full SiPM bias. Spec `Cc` ≥ bias voltage
  (this board: `0.22 µF 100 V X7R`, KEMET **C0805C224K1RACTU**); spec `Cf` similarly. An
  0805 100 V X7R is fine;
  do not drop the rating to hit a size.
- **Never 0805** (different package): Cremat SIP-8 modules, op-amps, trimpots, coax jacks,
  power/HV connectors.

---

## Key components per channel

| Class | Ref(s) | Part | Package | Always fitted? |
|---|---|---|---|---|
| Charge-sens. preamp | `U_CSP` | Cremat **CR-112** (ref. board used CR-113) | SIP-8 module, **socketed** | yes (plugged in) |
| Shaping amp | `U_SHAPER` | Cremat **CR-200-1µs** | SIP-8 module, **socketed** | yes (plugged in) |
| Baseline restorer | `U_BLR` | Cremat **CR-210** | SIP-8 module, **socketed** | **optional** |
| Module sockets | (one per module site) | **Samtec SS-108-TT-2** SIP-8 socket (alt Harwin D01-9970842) | `PinSocket_1x08_P2.54mm_Vertical` | yes — **36/board** (3 × 12) |
| Output buffer | `U_BUF` | **TI THS3491** CFA line driver | 8-pin SOIC/PowerPAD | **DNP by default** (0R-bypassed) |
| AC coupling | `Cc` | 0.22 µF 100 V **X7R**, KEMET **C0805C224K1RACTU** (bias ≤ 70 V; keep 100 V) | 0805 | yes |
| Bias filter R | `Rf1`,`Rf2` | **10 kΩ** each (VUV4; [circuit-design.md](circuit-design.md)) | 0805 | **optional** |
| Bias filter C | `Cf` | **100 nF, 100 V, X7R** | 0805 | **optional** |
| Bias-filter bypass | `JP_Rf1`,`JP_Rf2` | 0R | 0805 | **optional** |
| BLR bypass | `JP_BLR` | 0R | 0805 | **optional** |
| P/Z trim | `RV_PZ` | **Bourns 3296W** 200 kΩ 25-turn trimpot | TH trim | yes (**12/board**) |
| Source termination | `R_OUT` | 49.9 Ω | 0805 | yes |
| Decoupling | `C_*` | 0.1 µF / 1 µF / 10 µF | 0805 | yes |
| `BIAS_IN`,`SIPM`,`TEST`,`OUT_50` jacks | `J_BIAS`,`J_SIPM`,`J_TEST`,`J_OUT` | MCX TE Linx `CONMCX013` (DK `343-CONMCX013-ND`) | edge SMT | yes (×4) |

Multiply per-channel quantities by **12** (→ **48 MCX**), then add the shared power-entry
parts once. `BIAS_IN` is per-channel, so its jack is in the per-channel count, not shared.

---

## DNP / populate tables (the optional logic)

Two independent options, **per channel**. Exactly one path in each pair is populated.

### Option A — bias filter

| Variant | `Rf1` | `Rf2` | `Cf` | `JP_Rf1` | `JP_Rf2` |
|---|---|---|---|---|---|
| **Filter fitted** | ● | ● | ● | DNP | DNP |
| **Filter bypassed** | DNP | DNP | DNP | ● (0R) | ● (0R) |

### Option B — CR-210 baseline restorer

| Variant | `U_BLR` | `U_BLR` decoupling | `JP_BLR` |
|---|---|---|---|
| **BLR fitted** | ● | ● | DNP |
| **BLR bypassed** | DNP | DNP | ● (0R) |

> **Rule of thumb:** a `JP_*` 0R and the block it bypasses are **mutually exclusive** —
> never populate both (it would short out / parallel the block). Encode this in the BOM
> `DNP` column and re-check after any schematic change. This pair-wise exclusivity is the
> single most important assembly invariant on the board.

---

## Board-level (shared) parts

| Class | Part | Notes |
|---|---|---|
| Bulk decoupling | 10 µF + 100 µF electrolytic per rail | At ±Vs entry |
| Power in `J_PWR` | **3-pos 5.08 mm Phoenix screw terminal** | ±Vs, GND supply in |
| Daisy-chain out `J_DAISY` | **3-pos 5.08 mm Phoenix screw terminal** | Raw ±Vs, GND out to the next 1U box (not the only shared connector) |
| Mounting | M3 holes / standoffs (off the case bottom cover) | Per outline |

---

## Sourcing notes

- **Cremat modules** are sourced from Cremat Inc. / distributors (e.g. Advatech UK, FAST
  ComTec). Long-ish lead time — order early. Parts chosen (D4): CSP **CR-112**, shaper
  **CR-200-1µs**, BLR **CR-210**. ×12 each (CR-210 ×12 only if the BLR-fitted variant).
- BOMs with supplier info ship in the references — `reference/cremat-x6-board/` and the
  Cremat eval boards `reference/cremat-CR-160-R7/CR-160-R7 BOM.xls` (CR-200/CR-210/buffer)
  and `reference/cremat-CR-150-R5/CR-150-R5 BOM.xls` (CR-11X). Reuse those line items for
  the parts carried forward, updating passive sizes to 0805.
- Generate the final fielded BOM from KiCad (see
  [../fabrication/fabrication-guide.md](../fabrication/fabrication-guide.md)); keep
  `pcbfab/`/`assembly/` outputs out of git (`.gitignore`), regenerate before each order.

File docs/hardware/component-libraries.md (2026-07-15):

# Component Libraries

Symbols and footprints the hardware track needs to provide. Keep project-local, datasheet-
verified libraries (the `ets-breakout` / reference-board convention), referenced with
`${KIPRJMOD}` so the project is portable.

---

## Canonical sources (reuse, don't redraw)

Four reference submodules carry verified symbols/footprints for the parts we keep. Prefer
the **upstream Cremat eval boards** (clean, authoritative) over the x6-board's rescue libs:

| Part | Canonical source | Asset to copy |
|---|---|---|
| CR-11X CSP (CR-110/-111/-112/-113) | `reference/cremat-CR-150-R5` (`CR-150-R5-cache.lib`) | symbol + BOM (footprint = stock `PinSocket_1x08`, see below) |
| CR-200-X shaper | `reference/cremat-CR-160-R7` (`CR-160-R7-cache.lib`) | symbol (footprint = stock `PinSocket_1x08`, see below) |
| **CR-210 BLR** | `reference/cremat-CR-160-R7` (`CR-160-R7-cache.lib`) | symbol (pinout confirmed); footprint = stock `PinSocket_1x08` |
| Output buffer — **TI THS3491** (CFA) | *not from the Cremat refs* (replaces EL5163/EL5167) | new symbol + SOIC-8/PowerPAD footprint — see *New parts to add* |

The `reference/cremat-x6-board/` project also has these (as KiCad "rescue" symbols), plus
the passive/jumper/connector symbols below — fine to reuse, but re-home them into a clean
project lib and drop the rescue/absolute paths.

| Symbol (x6-board lib) | Part | Carried forward |
|---|---|---|
| `CR-11X` (`CR-150-R5-rescue`) | Cremat CR-110/-111/-112/-113 CSP (SIP-8) | yes |
| `CR-200` (`CR-160-R7-rescue`) | Cremat CR-200-X shaper (SIP-8) | yes |
| `EL5163`/`EL5167` | old output buffer — **replaced by TI THS3491** (new part, below) | no |
| `Device:R_US`, `Device:C`, `Device:L` | passives | yes (footprints → 0805) |
| `Device:R_Potentiometer_Trim_US` | trimpots | yes |
| `Jumper:SolderJumper_2_Bridged`, `Jumper_2_Open`, `Jumper_3_Open` | jumpers | yes (for 0R bypass) |
| `Connector:Conn_Coaxial` | `SIPM` / `OUT` jacks | yes |
| `power:+VDC`, `power:-VDC`, `power:GND` | rails | yes |

> The reference symbols come from KiCad "rescue" libs with embedded definitions — they
> open fine, but re-home them into a clean project lib (`lib/cremat.kicad_sym`) and drop
> the absolute-path rescue references, the cleanup `ets-breakout` documents for its own
> rescue lib.

---

## New parts to add

### Cremat CR-210 baseline restorer (NEW — symbol available, pinout confirmed)
- **Symbol:** copy the `CR-210` symbol straight from `reference/cremat-CR-160-R7`
  (`CR-160-R7-cache.lib`). Confirmed pinout `1=input, 2=GND, 3=GND, 4=-Vs, 5=+Vs, 6=GND,
  7=GND, 8=output` — identical to the CR-200 except pin 2 (P/Z → GND), so don't reuse the
  CR-200 symbol as-is.
- **Footprint (module sites are *socketed*):** the CR-112, CR-200, and CR-210 all **plug into
  SIP-8 sockets and are never soldered.** Use the stock KiCad **`PinSocket_1x08_P2.54mm_Vertical`**
  footprint (0.1" pitch) populated with a **Samtec SS-108-TT-2** SIP-8 socket (alt Harwin
  D01-9970842) — **36 per board** (3 module sites × 12). One socket footprint serves all three
  module types. (The reference boards' `8pinSIP` / `PinHeader_1x08` footprints described
  *soldered* modules and are **not** used here.)

### Output buffer — TI THS3491 (NEW — replaces the EL5163/EL5167)
- **Symbol:** the buffer is now a **TI THS3491** current-feedback line driver — **not** the
  EL5163/EL5167/LM7321 the reference boards carried (that part could not run on the ±12 V
  rails). Use a KiCad standard op-amp/CFA symbol or a TI-provided symbol; verify pin mapping
  against the THS3491 datasheet.
- **Footprint:** **8-pin SOIC with PowerPAD** thermal pad (DK `296-49085-1-ND`, cut tape).
- **Populate option:** DNP by default with a 0R bypass link (see [bom.md](bom.md) /
  [channel.md](channel.md)).

### 0R bypass jumpers (0805)
- Use a standard **`R_0805_2012Metric`** footprint stuffed with a 0R link for
  `JP_Rf1`,`JP_Rf2`,`JP_BLR`, **or** a 2-pad solder-jumper footprint for the tightest
  spots. Symbol: a resistor (0R) or `SolderJumper_2`.

### 0805 passive footprints
- Standardize R/C on `R_0805_2012Metric` / `C_0805_2012Metric`. For the HV parts (`Cc`,
  `Cf`) use the same 0805 footprint but a voltage-rated MLCC part number in the BOM.

### Connectors
- One MCX part serves all **four** per-channel I/O jacks (`BIAS_IN`, `SIPM`, `TEST`, `OUT`)
  — **48 per board** (4 × 12): **TE Connectivity Linx `CONMCX013`** (DK `343-CONMCX013-ND`),
  50 Ω female board-edge SMT. Import a
  datasheet-verified footprint + 3D model (verify the edge cutout against the TE drawing),
  as `ets-breakout` did for its coax jacks. No separate HV connector — `BIAS_IN` uses the
  same MCX.

---

## Library files to create

```
hardware/
  lib/
    cremat.kicad_sym         CR-11X, CR-200, CR-210 symbols (re-homed) + THS3491 buffer
    cremat.pretty/           MCX coax jack + 0R jumper footprints (SIP-8 module sites use the
                             stock KiCad PinSocket_1x08 footprint, not a project-local one)
  fp-lib-table               registers cremat.pretty via ${KIPRJMOD}
  sym-lib-table              registers cremat.kicad_sym via ${KIPRJMOD}
```

Verify each footprint against the part drawing before routing — datasheet-verified
footprints are an iron rule inherited from both reference projects.

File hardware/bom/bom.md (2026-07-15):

# Fielded BOM — Multi-channel Cremat Amplifier (Track 1 deliverable)

Per-channel parts ×12 + shared parts, for the **Full build variant** (bias filter fitted +
CR-210 fitted; all `JP_*` 0R bypasses DNP **except `JP_BUF`** — the THS3491 output buffer
is DNP by default and its 0R bypass is fitted). Policy/rationale is in
[../../docs/hardware/bom.md](../../docs/hardware/bom.md); designed values are in
[../../docs/hardware/circuit-design.md](../../docs/hardware/circuit-design.md).

> The front-end, modules, output termination, optional jumpers, trimpots, and connectors
> below are fixed. The CR-200→buffer **support passives + per-rail decoupling** carry over
> from the reference channel (`reference/cremat-x6-board/channel.kicad_sch`) and are
> finalized when Track 5 captures the schematic and exports the authoritative netlist BOM.

## Per-channel (×12)

| Ref (per ch) | Value | Footprint (KiCad lib) | MPN / source | Qty/ch | Qty×12 | Populate (Full) |
|---|---|---|---|---|---|---|
| `U_CSP` | Cremat **CR-112** (plugs into socket) | — plugs into the SIP-8 socket below | Cremat CR-112 *(owned)* | 1 | 12 | ● |
| `U_SHAPER` | Cremat **CR-200-1µs** (plugs in) | — plugs into the SIP-8 socket below | Cremat CR-200-1µs *(owned)* | 1 | 12 | ● |
| `U_BLR` | Cremat **CR-210** (plugs in) | — plugs into the SIP-8 socket below | Cremat CR-210 *(owned)* | 1 | 12 | ● |
| module socket (×3/ch) | **SIP-8 socket** carrying the 3 modules above (soldered; modules never soldered) | `Connector_PinSocket_2.54mm:PinSocket_1x08_P2.54mm_Vertical` | Samtec **SS-108-TT-2** (alt Harwin D01-9970842) | 3 | 36 | ● |
| `U_BUF` | **TI THS3491** CFA output buffer | `Package_SO:SOIC-8-1EP_3.9x4.9mm_P1.27mm_EP2.29x3mm` (SOIC-8 PowerPAD — confirm EP size vs DDA land) | TI **THS3491** (DK 296-49085-1-ND) | 1 | 12 | **DNP** |
| `JP_BUF` | **0 Ω** (buffer bypass) | `Resistor_SMD:R_0805_2012Metric` | 0R 0805 jumper | 1 | 12 | ● |
| `Cc` | **0.22 µF 100 V X7R** | `Capacitor_SMD:C_0805_2012Metric` | KEMET **C0805C224K1RACTU** (alt Murata GRM21AR72A224KAC5K) | 1 | 12 | ● |
| `Rf1`,`Rf2` | **10 kΩ** | `Resistor_SMD:R_0805_2012Metric` | any 1 % 0805 | 2 | 24 | ● |
| `Cf` | **100 nF 100 V X7R** | `Capacitor_SMD:C_0805_2012Metric` | any 100 V 0805 | 1 | 12 | ● |
| `JP_Rf1`,`JP_Rf2` | **0 Ω** (filter bypass) | `Resistor_SMD:R_0805_2012Metric` | 0R 0805 jumper | 2 | 24 | **DNP** |
| `JP_BLR` | **0 Ω** (CR-210 bypass) | `Resistor_SMD:R_0805_2012Metric` | 0R 0805 jumper | 1 | 12 | **DNP** |
| `R_OUT` | **49.9 Ω** | `Resistor_SMD:R_0805_2012Metric` | 49.9 R 1 % 0805 | 1 | 12 | ● |
| `RV_PZ` | 200 kΩ trim (pole-zero, 25-turn) | `Potentiometer_THT:Potentiometer_Bourns_3296W_Vertical` | Bourns 3296W-204 | 1 | 12 | ● |
| `J_BIAS`,`J_SIPM`,`J_TEST`,`J_OUT` | MCX edge jack (`BIAS`/`SIPM`/`TEST`/`OUT_50`) | `cremat:MCX_CONMCX013-T` | TE Linx **CONMCX013** (DK 343-CONMCX013-ND) | 4 | 48 | ● |
| decoupling | 0.1 µF / 1 µF / 10 µF (per module rails) | `Capacitor_SMD:C_0805_2012Metric` | per reference | ~4 | ~48 | ● |
| buffer support R | THS3491 CFA gain-set (`Rf`/`Rg`) + decoupling | `Resistor_SMD:R_0805_2012Metric` | per THS3491 datasheet | several | — | fit w/ `U_BUF` |

## Shared (×1 per board)

| Ref | Value | Footprint (KiCad lib) | MPN / source | Qty |
|---|---|---|---|---|
| `J_PWR` | 3-pos 5.08 mm screw terminal — **supply in** (+Vs/−Vs/GND) | `TerminalBlock_Phoenix:TerminalBlock_Phoenix_MKDS-1,5-3-5.08_1x03_P5.08mm_Horizontal` | Phoenix MKDS 1,5/3-5.08 | 1 |
| `J_DAISY` | 3-pos 5.08 mm screw terminal — **raw rails out** to the next 1U box | `TerminalBlock_Phoenix:TerminalBlock_Phoenix_MKDS-1,5-3-5.08_1x03_P5.08mm_Horizontal` | Phoenix MKDS 1,5/3-5.08 | 1 |
| `C_BULK+`,`C_BULK-` | 10 µF + 100 µF electrolytic / rail | `Capacitor_THT:CP_Radial_D6.3mm_P2.50mm` | per rail | 4 |
| `H1..H4` | M3 mounting hole | `MountingHole:MountingHole_3.2mm_M3` | — | 4 |

## Module summary (Cremat — already owned, socketed)

| Part | Qty (12-ch, Full) | Notes |
|---|---|---|
| CR-112 | 12 | charge-sensitive preamp |
| CR-200-1µs | 12 | 1 µs Gaussian shaper |
| CR-210 | 12 | baseline restorer (omit if a No-BLR build) |

**All three module types are already owned** (qty 12 each). They **plug into the
SS-108-TT-2 sockets** (never soldered) and are **not part of the JLCPCB fab/assembly
order**. For reference, the 2026-01 Cremat US list (qty-12 tier) is CR-112 $55 /
CR-200-1µs $55 / CR-210 $77 ⇒ ~$2,244/board.

## DNP by build variant

| Variant | `Rf1/Rf2/Cf` | `JP_Rf1/JP_Rf2` | `U_BLR` | `JP_BLR` |
|---|---|---|---|---|
| **Full** (first build) | ● | DNP | ● | DNP |
| No-BLR | ● | DNP | DNP | ● |
| External-bias | DNP | ● | ● | DNP |
| Reference-equiv | DNP | ● | DNP | ● |

Invariant: a `JP_*` 0R and the block it bypasses are **mutually exclusive** — never both.

The **THS3491 output buffer (`U_BUF`) is DNP by default in every variant above** — `JP_BUF`
= 0R is fitted so the shaper/BLR drives the 49.9 Ω back-termination directly. Populate
`U_BUF` (and its gain-set `Rf`/`Rg`) and DNP `JP_BUF` only when a buffered 50 Ω output is
required. This buffer↔`JP_BUF` pair obeys the same mutual-exclusion invariant.

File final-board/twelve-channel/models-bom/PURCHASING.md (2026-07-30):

# Purchase-ready BOM — 12-channel Cremat amplifier (`twelve-channel`)

> Sourcing verified **2026-07-11** (DigiKey PNs/prices/stock read live; Mouser second-source URLs confirmed, some prices distributor-blocked from scraping). Prices are **DigiKey qty-1 USD** — passives are far cheaper at strip/reel quantities. Generated by `gen_purchasing.py` from `twelve-channel-bom.csv`.

**Board:** 213.2 x 334.7 mm, 4-layer. **Primary build: 2 boards per 2U case** (see ORDERING.md); this all-DigiKey reference costs one case per board.

## Cost summary (one board)

| Group | Qty (parts) | Subtotal (qty-1) |
|---|--:|--:|
| Cremat modules (CR-112 / CR-200 / CR-210) | 36 | $2,244.00 |
| DigiKey/Mouser catalog parts (FIT) | 344 | $273.12 |
| **Default build subtotal (FIT only)** | **380** | **$2,517.12** |
| Optional output-buffer block (THS3491 + 976R, DNP) | 36 | $221.76 |
| Other DNP (variant jumpers/spares) | 84 | $11.52 |
| Enclosure (Hammond RM2U1908VBK 2U; primary = 1 box per 2 boards) | 1 | $198.73 |

- **One board, default build + its 2U case:** ~$2,715.85 ($2,517.12 parts + one $198.73 case).
- **Fully buffered board (add THS3491 block):** ~$2,738.88 parts.
- The BOM is **Cremat-module dominated** (~89% of parts cost); passives are noise.

## 1. Cremat modules — order direct from Cremat Inc

Not DigiKey/Mouser parts. Order at [cremat.com](https://www.cremat.com/ordering/united-states/): **Amazon** store for <=10 pcs, or **email** Cremat (info@cremat.com — verify on site; one page lists Cremat.Inc@gmail.com) with PNs+qty for >10 pcs; they invoice (card). Ph +1 617-527-6590. **Long lead — order these first.**

| Value | MPN | Qty | $ea (q1) | $ext | Qty breaks | Product page |
|---|---|--:|--:|--:|---|---|
| CR-210 | CR-210-R0 | 12 | $77.00 | $924.00 | 2026-01 list: $86 (1-9) / $77 (10-99) / $73.10 (100+); qty 12 = $77 | [cremat.com](https://www.cremat.com/home/cr-210-baseline-restorer-blr/) |
| CR-112 | CR-112-R2.1 | 12 | $55.00 | $660.00 | 2026-01 list: $65 (1-9) / $55 (10-99) / $47 (100+); qty 12 = $55 | [cremat.com](https://www.cremat.com/home/charge-sensitive-preamplifiers/) |
| CR-200-1us | CR-200-1us-R2.1 | 12 | $55.00 | $660.00 | 2026-01 list: $65 (1-9) / $55 (10-99) / $47 (100+); qty 12 = $55 | [cremat.com](https://www.cremat.com/home/cr-200-x-shaper-modules/) |

## 2. DigiKey / Mouser catalog parts (default-populated)

| Value | MPN | DigiKey PN | Qty | $ea | $ext | Mouser | Stock | Notes |
|---|---|---|--:|--:|--:|---|--:|---|
| MCX edge jack 50R | CONMCX013 | [343-CONMCX013-ND](https://www.digikey.com/en/products/detail/te-connectivity-linx/CONMCX013/13245481) | 48 | $3.22 | $154.56 | [CONMCX013-T](https://www.mouser.com/ProductDetail/Linx-Technologies/CONMCX013-T) | 1,050 | **PRIMARY PLAN: JLC assembles BWMCX-KEF (BAT WIRELESS, LCSC C5250059, $0.49) in STANDARD tier on J1–J48 — see ORDERING.md.** This DigiKey CONMCX013 line applies *only* in the all-hand-solder fallback (skipping JLC assembly). Same Linx CONMCX013 land pattern either way (BWMCX-KEF is a verified drop-in). TE-direct: te.com CONMCX013. |
| SIP-8 socket | SS-108-TT-2 | [612-SS-108-TT-2-ND](https://www.digikey.com/en/products/detail/samtec-inc/SS-108-TT-2/1105712) | 36 | $1.17 | $42.12 | [200-SS108TT2](https://www.mouser.com/ProductDetail/Samtec/SS-108-TT-2) | 649 (DK; ~4.4k all distys) | SIP-8 socket under every Cremat module (solder socket, plug module). Cremat's own eval-board part (CR-160 BOM SAM1119-08-ND). $1.37 (1) / $1.17 (10-99) / $0.99 (100+). Verified alt: Harwin D01-9970842 (gold flash, DK D01-9970842-ND, ~3.9k stk, $0.75 @ 40). Mouser has only 6 pcs - buy from DigiKey. |
| 200k | 3296W-1-204LF | [3296W-204LF-ND](https://www.digikey.com/en/products/detail/bourns-inc/3296W-1-204LF/1088052) | 12 | $2.44 | $29.28 | [652-3296W-1-204LF](https://www.mouser.com/ProductDetail/Bourns/3296W-1-204LF) | 80 (DK; ~1.5k Mouser, 19 wk DK lead) |  |
| 10uF 25V X5R | C0805C106K3PACTU | [399-11939-1-ND](https://www.digikey.com/en/products/detail/kemet/C0805C106K3PACTU/5267604) | 72 | $0.23 | $16.56 | [C0805C106K3PACTU](https://www.mouser.com/ProductDetail/KEMET/C0805C106K3PACTU) | 253,633 |  |
| 4.7 | RC0805JR-074R7L | [311-4.7ARCT-ND](https://www.digikey.com/en/products/detail/yageo/RC0805JR-074R7L/731273) | 72 | $0.10 | $7.20 | [603-RC0805JR-074R7L](https://www.mouser.com/ProductDetail/YAGEO/RC0805JR-074R7L) | ~142,966 |  |
| 0.22uF 100V X7R | C0805C224K1RACTU | [399-C0805C224K1RACTUCT-ND](https://www.digikey.com/en/products/detail/kemet/C0805C224K1RACTU/2211772) | 12 | $0.49 | $5.88 | [80-C0805C224K1RAC](https://www.mouser.com/ProductDetail/KEMET/C0805C224K1RACTU) | ~95k | PRIMARY since 2026-07-11 (Murata GRM21AR72A224KAC5K went DK 0-stock, 17-wk lead; Murata = equal-spec alt via Mouser 81-GRM21AR72A224KAC5K). 100V X7R 0805 HV coupling. |
| Screw terminal 3-pos 5.08mm | 1715734 | [277-1264-ND](https://www.digikey.com/en/products/detail/phoenix-contact/1715734/260632) | 2 | $1.71 | $3.42 | [651-1715734](https://www.mouser.com/ProductDetail/Phoenix-Contact/1715734) | 1,986 |  |
| 10k | RC0805FR-0710KL | [311-10.0KCRCT-ND](https://www.digikey.com/en/products/detail/yageo/RC0805FR-0710KL/730482) | 24 | $0.10 | $2.40 | [603-RC0805FR-0710KL](https://www.mouser.com/ProductDetail/YAGEO/RC0805FR-0710KL) | 3,586,722 |  |
| 470uF 35V | EEE-FN1V471UP | [10-EEE-FN1V471UPCT-ND](https://www.digikey.com/en/products/detail/panasonic-industry/EEE-FN1V471UP/11657045) | 2 | $1.17 | $2.34 | [667-EEE-FN1V471UP](https://www.mouser.com/ProductDetail/Panasonic/EEE-FN1V471UP) | 2,569 |  |
| SSA24 | SSA24 | [SSA24CT-ND](https://www.digikey.com/en/products/detail/onsemi/SSA24/5305051) | 2 | $0.84 | $1.68 | [512-SSA24](https://www.mouser.com/ProductDetail/onsemi-Fairchild/SSA24) | 15,991 |  |
| PTC 1.1A 24V | 1812L110/24DR | [F5632CT-ND](https://www.digikey.com/en/products/detail/littelfuse-inc/1812L110-24DR/2520731) | 2 | $0.78 | $1.56 | [576-1812L110/24DR](https://www.mouser.com/ProductDetail/Littelfuse/1812L110-24DR) | 1,503 |  |
| 1pF 50V C0G | CC0805CRNPO9BN1R0 | [311-1089-1-ND](https://www.digikey.com/en/products/detail/yageo/CC0805CRNPO9BN1R0/302823) | 12 | $0.11 | $1.32 | [link](https://www.mouser.com/c/?q=CC0805CRNPO9BN1R0) | 43,415 |  |
| 0R | RC0805JR-070RL | [311-0.0ARCT-ND](https://www.digikey.com/en/products/detail/yageo/RC0805JR-070RL/731163) | 12 | $0.10 | $1.20 | [603-RC0805JR-070RL](https://www.mouser.com/ProductDetail/YAGEO/RC0805JR-070RL) | 1,165,597 |  |
| 100nF 100V X7R | CL21B104KCFNNNE | [1276-6840-1-ND](https://www.digikey.com/en/products/detail/samsung-electro-mechanics/CL21B104KCFNNNE/5961324) | 12 | $0.10 | $1.20 | [187-CL21B104KCFNNNE](https://www.mouser.com/ProductDetail/Samsung-Electro-Mechanics/CL21B104KCFNNNE) | 566,243 |  |
| 47 | RC0805JR-0747RL | [311-47ARCT-ND](https://www.digikey.com/en/products/detail/yageo/RC0805JR-0747RL/728335) | 12 | $0.10 | $1.20 | [603-RC0805JR-0747RL](https://www.mouser.com/ProductDetail/YAGEO/RC0805JR-0747RL) | 95,764 |  |
| 49.9 | RC0805FR-0749R9L | [311-49.9CRCT-ND](https://www.digikey.com/en/products/detail/yageo/RC0805FR-0749R9L/727984) | 12 | $0.10 | $1.20 | [603-RC0805FR-0749R9L](https://www.mouser.com/ProductDetail/YAGEO/RC0805FR-0749R9L) | 358,924 |  |

## 3. Not-populated by default (buffer option + variant jumpers)

The **output buffer** (THS3491 + 976R Rf) is DNP — bypassed by a 0R jumper. Populate the whole block for the +2 gain stage (OUT_50 ~134 mV/pC vs ~67 mV/pC bypassed). Other DNP rows are the filter-bypass / spare passives.

| Value | MPN | DigiKey PN | Qty | $ea | $ext | Block | Notes |
|---|---|---|--:|--:|--:|---|---|
| THS3491 | THS3491IDDAT | [296-49085-1-ND](https://www.digikey.com/en/products/detail/texas-instruments/THS3491IDDAT/9091882) | 12 | $18.28 | $219.36 | BUFFER | CUT TAPE 296-49085-1-ND ($18.28 q1). Do NOT order 296-49085-2-ND - that is a 250-pc reel (~$3k). TI-direct: ti.com THS3491IDDAT. |
| 976 | RC0805FR-07976RL | [311-976CRCT-ND](https://www.digikey.com/en/products/detail/yageo/RC0805FR-07976RL/728214) | 24 | $0.10 | $2.40 | BUFFER |  |
| 10uF 25V X5R | C0805C106K3PACTU | [399-11939-1-ND](https://www.digikey.com/en/products/detail/kemet/C0805C106K3PACTU/5267604) | 24 | $0.23 | $5.52 | CSP |  |
| 0R | RC0805JR-070RL | [311-0.0ARCT-ND](https://www.digikey.com/en/products/detail/yageo/RC0805JR-070RL/731163) | 36 | $0.10 | $3.60 | CSP |  |
| 4.7 | RC0805JR-074R7L | [311-4.7ARCT-ND](https://www.digikey.com/en/products/detail/yageo/RC0805JR-074R7L/731273) | 24 | $0.10 | $2.40 | CSP |  |

## 4. Enclosure — Hammond 2U rack case

- **Order:** Hammond Manufacturing **RM2U1908VBK** — DigiKey [HM1166-ND](https://www.digikey.com/en/products/detail/hammond-manufacturing/RM2U1908VBK/1963303) **$198.73** (96 in stock) · Hammond [part page](https://www.hammfg.com/part/RM2U1908VBK). *(Switched 1U→2U 2026-07-30 for board-stack clearance.)*
- 2U 19-in rack case, VENTED black (Ø4.3 mm holes - EMI-negligible in the 1.6k-130 kHz band, needed for the ~13 W dissipation). **Primary build (ORDERING.md) stacks 2 boards in ONE 2U box** on standoffs (~1 inch between boards). Ext 203.2 D x 421.6 W x 88.13 H mm; interior depth 196.85 / height 84.53 / width 415.30 mm (Hammond drawing, verified 2026-07-30). Solid-cover alt: RM2U1908SBK (DK HM998-ND, ~$189.67). Board depth (213.2 mm) vs 196.85 mm interior sets the MCX recess at the front/rear panels. Mount on standoffs through the 4 M3 corner holes off the bottom cover.

## 5. DigiKey quick-add (default build, one board)

Paste into DigiKey **myLists > Quick Add** (`PN, qty` per line). Buffer parts omitted (DNP); add `296-49085-1-ND, 12` and `311-976CRCT-ND, 24` if populating the buffer. Passive qtys are exact-fit — pad for spares / buy strips.

```
343-CONMCX013-ND, 48
612-SS-108-TT-2-ND, 36
3296W-204LF-ND, 12
399-11939-1-ND, 72
311-4.7ARCT-ND, 72
399-C0805C224K1RACTUCT-ND, 12
277-1264-ND, 2
311-10.0KCRCT-ND, 24
10-EEE-FN1V471UPCT-ND, 2
SSA24CT-ND, 2
F5632CT-ND, 2
311-1089-1-ND, 12
311-0.0ARCT-ND, 12
1276-6840-1-ND, 12
311-47ARCT-ND, 12
311-49.9CRCT-ND, 12
HM1166-ND, 1
```

_Cremat modules (CR-112 x12, CR-200-1us x12, CR-210 x12) are ordered separately from cremat.com._

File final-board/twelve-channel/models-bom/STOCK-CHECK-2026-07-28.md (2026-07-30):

# LCSC / JLCPCB assembly stock check — 2026-07-28

Live check of the 12 assembled SMD line items in
[`design/fab/jlc/bom-twelve-channel-jlc.csv`](../design/fab/jlc/bom-twelve-channel-jlc.csv)
ahead of a JLCPCB SMT assembly order. Stock figures are **LCSC retail** (via web, 2026-07-28).
Quantities are the whole 12‑channel board × the planned **2‑board** assembly build.

> **CRITICAL — read before acting on "Out of Stock" below.**
> **LCSC retail stock and JLCPCB SMT‑assembly stock are SEPARATE inventory pools for the same
> C‑number.** JLC stocks its assembly feeders independently of LCSC's retail reels — a part can
> read "Out of Stock" for LCSC retail purchase and still be fully available for JLC SMT assembly
> (this is normal for JLC **Basic** parts). The figures below are therefore an *indicator*, not
> the assembly-side truth. **The authoritative check is uploading this BOM to JLCPCB's SMT order
> tool**, which validates each part against the *assembly* pool and auto-suggests replacements.

## Resolution (2026-07-28, same day)

The three LCSC-OOS lines were re-sourced to fetch-verified in-stock parts and the BOM
[`bom-twelve-channel-jlc.csv`](../design/fab/jlc/bom-twelve-channel-jlc.csv) updated in place
(placement count unchanged at 246). Each replacement was confirmed by fetching its LCSC page twice
(sourcing agent + independent re-fetch):

| Line | Was (OOS) | Now | Mfr / MPN | LCSC stock | JLC class |
|---|---|---|---|--:|---|
| 10 k 1% 0805 | C17414 | **C84376** | YAGEO RC0805FR-0710KL | 1,032,300 | Basic |
| 4.7 Ω 0805 | C17675 | **C2933459** | FOJAN FRC0805F4R70TS (±1%) | 347,700 | **Extended** ⚠ |
| 470 µF 35 V | *(kept)* | **C494847** | Panasonic EEE-FN1V471UP | LCSC 0 / **JLC-assembly YES** | Extended |

- **10 k → C84376**: the design's own DigiKey MPN (YAGEO RC0805FR-0710KL) and a JLC Basic part —
  ideal drop-in.
- **4.7 Ω → C2933459**: the only Basic 4.7 Ω (C17675) is gone, so this is Extended (+$3 feeder).
  **Revert to C17675 at upload if JLC's assembly pool still has it Basic** — see ORDERING.md ⚠.
- **470 µF → kept C494847** (Panasonic). *Correction (2026-07-28, at JLC upload):* the earlier
  LCSC-retail substitute **C72519 came up "unmatched"** in JLC's Economic assembly tier — verified
  via jlcpcb.com/partdetail that C72519 is **"Standard-only" PCBA** (not in the Economic feeder
  library), whereas **C494847 is "Economic + Standard" PCBA**. For a JLC *assembly* order the part
  must be in JLC's assembly library; **LCSC-retail stock is the wrong criterion for electrolytics**
  (JLC assembles from its own feeder pool — C494847's LCSC-retail 0 does not matter). Reverted the
  BOM to C494847. The 10 k (C84376) and 4.7 Ω (C2933459) matched fine, so they stay.
  **General rule for JLC assembly BOMs: pick parts that jlcpcb.com/partdetail lists as
  "Economic and Standard" PCBA, not just LCSC-in-stock.**

Higher-grade alternates on file if wanted: 4.7 Ω YAGEO RC0805FR-074R7L = **C137513** (48 k, 1%);
470 µF AEC-Q200 ROQANG = **C5162352** (D10×10.5, 2.6 k). All fetch-verified in stock 2026-07-28.
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

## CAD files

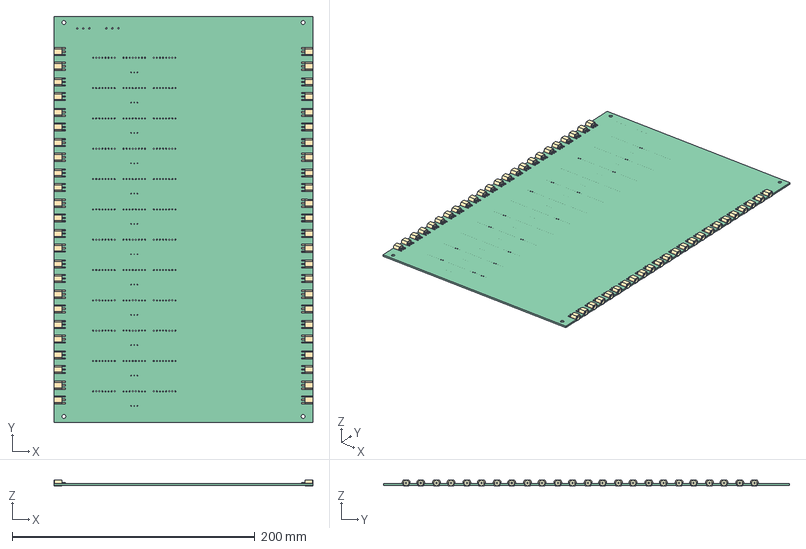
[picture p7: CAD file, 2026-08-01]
final-board/twelve-channel/design/twelve-channel-twelve-channel.step
213.2 x 334.7 x 5.00 mm
Local_CS_2082
Pcb_2082
PCB_Sketch_2082
CONMCX013
CONMCX014
CONMCX015
CONMCX016
CONMCX017
CONMCX018
CONMCX019
CONMCX020
CONMCX021
CONMCX022
CONMCX023
CONMCX024
CONMCX025
CONMCX026
CONMCX027
CONMCX028
CONMCX029
CONMCX030
CONMCX031
CONMCX032
CONMCX033
CONMCX034
CONMCX035
CONMCX036
CONMCX037
CONMCX038
CONMCX039
CONMCX040
CONMCX041
CONMCX042
CONMCX043
CONMCX044
CONMCX045
CONMCX046
CONMCX047
CONMCX048
CONMCX049
CONMCX050
CONMCX051
CONMCX052
CONMCX053
CONMCX054
CONMCX055
CONMCX056
CONMCX057
CONMCX058
CONMCX059
CONMCX060
CONMCX061
CONMCX062
CONMCX063
CONMCX064
CONMCX065
CONMCX066
CONMCX067
CONMCX068
CONMCX069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

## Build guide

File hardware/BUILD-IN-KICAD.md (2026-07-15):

# Building the board in KiCad (Tracks 5 → 6 → 7)

> **Superseded 2026-07-11.** The board was ultimately built via `integration/single-channel/`
> → `final-board/twelve-channel/` (213.2 × 334.7 mm, 4-layer, order-ready), not this `hardware/`
> skeleton. Use `final-board/twelve-channel/` (HANDOFF.md, ORDERING.md) as the source of truth;
> the steps below describe the earlier `hardware/`-track plan.

Everything up to schematic capture is done and validated: the symbol library
([lib/cremat.kicad_sym](lib/cremat.kicad_sym)), the project + net classes
([multi-channel-cremat-amplifier.kicad_pro](multi-channel-cremat-amplifier.kicad_pro)),
the lib tables, the fielded BOM ([bom/](bom/)), the per-channel netlist
([integration-notes.md](integration-notes.md)), and the mechanical envelope
([mechanical.md](mechanical.md)).

**Update — Track 5 is now generated headless and ERC-clean** (see
[../docs/KICAD_WITH_CLAUDE_CODE.md](../docs/KICAD_WITH_CLAUDE_CODE.md)). The schematic is
produced by [gen_sch.py](gen_sch.py):
```
python hardware/gen_sch.py          # writes channel.kicad_sch + multi-channel-cremat-amplifier.kicad_sch
bash scripts/erc.sh                 # ERC -> reports/erc_root.json (0 errors)
```
`kicad-cli sch erc` reports **0 errors** (4 warnings = MCX/screw-terminal footprint links).
The Track 5 steps below are now **optional GUI refinement** (e.g. swapping the unity-follower
buffer for the reference's exact gain/P-Z network, or tidying placement). **Tracks 6–7
(layout + fab) are the remaining work.** KiCad 10 is at `C:\Program Files\KiCad\10.0\`.

> Generator caveat: once you edit the schematic in the GUI, the `.kicad_sch` becomes the
> source of truth — don't re-run `gen_sch.py` (it overwrites). The generated buffer is a
> unity follower (clean + ERC-valid); the reference's gain/P-Z network is the documented
> GUI refinement.

---

## Track 5 — Schematic capture  *(done by gen_sch.py; below = optional GUI refinement)*

1. **Open the project** `multi-channel-cremat-amplifier.kicad_pro`. Confirm the `cremat`
   symbol lib resolves (Preferences → Manage Symbol Libraries → it's in the project table).
2. **Create `channel.kicad_sch`** (one hierarchical sheet) and capture **one channel** from
   [integration-notes.md](integration-notes.md):
   - Place: `J_BIAS`, `J_SIPM`, `J_OUT` (Conn_Coaxial), `Rf1`, `Rf2`, `Cf`, `JP_Rf1`,
     `JP_Rf2`, `Cc`, `U_CSP` (cremat:CR-11X), `U_SHAPER` (cremat:CR-200), `U_BLR`
     (cremat:CR-210), `JP_BLR`, `U_BUF` (cremat:THS3491xDDA, DNP by default), `R_OUT`, trimpots, decoupling.
   - Wire by the **net→pin table** in integration-notes.md. Internal nets (`BIAS_IN`,
     `N_filt`, `FE`, `CSP_IN`, `CSP_OUT`, `SH_OUT`, `PZ`, `BLR_OUT`, `BUF_OUT`, `OUT`) =
     local labels; `+VDC`/`-VDC`/`GND` = **hierarchical labels** (the only sheet ports).
   - **Bias filter** = `Rf1`+`Cf`+`Rf2`, with `JP_Rf1`∥`Rf1` and `JP_Rf2`∥`Rf2`.
   - **CR-210** between `SH_OUT` and `BLR_OUT`, with `JP_BLR`∥ the module.
   - **P/Z network + buffer**: copy the sub-circuit from
     `reference/cremat-x6-board/channel.kicad_sch` (open it side-by-side), resizing passives
     to 0805. That gives the exact gain/feedback/offset network.
   - Set `DNP` per the **Full** variant ([bom/bom.md](bom/bom.md)): `JP_Rf1/JP_Rf2/JP_BLR`
     DNP; everything else fitted.
3. **Root sheet** `multi-channel-cremat-amplifier.kicad_sch`: place **12 sheet instances**
   of `channel.kicad_sch` (`ch1..ch12`); wire all 12 sheets' `+VDC`/`-VDC`/`GND` pins to the
   rails; add `J_PWR` (3-pos screw terminal) and a **PWR_FLAG** on each of `+VDC`/`-VDC`/`GND`
   so ERC sees them driven.
4. **Annotate** → **assign footprints** per [bom/bom.md](bom/bom.md) (stock libs; create the
   one MCX footprint — see [lib/cremat.pretty/README.md](lib/cremat.pretty/README.md)).
5. **ERC** until 0 errors. Export the netlist + the BOM.

> Gate: ERC 0 errors. The net classes (`hv_bias` etc.) are already in the project.

---

## Track 6 — PCB layout

**The board is scaffolded headless** by [gen_pcb.py](gen_pcb.py) (KiCad bundled python):
```
"C:/Program Files/KiCad/10.0/bin/python.exe" hardware/gen_pcb.py   # 217 footprints + nets + outline + M3 + GND zone
bash scripts/drc.sh                                                # DRC -> reports/drc.json
```
That gives a `.kicad_pcb` with **every footprint placed and every net assigned** (from the
verified netlist), a 225×235 mm outline, 4× M3 holes, and an (unfilled) GND zone. **What it is
NOT:** routed, or arranged for manufacture — `pcbnew` has no autorouter, the parts sit on a
grid, and the edge-launch MCX cutouts must be moved to the board edge. So the GUI work is:

1. (Already done by gen_pcb.py: parts + nets imported.) Set the **stackup** (4-layer 1.6 mm
   recommended; ground plane under the analog chain).
2. **Outline ≈ 225 × 235 mm**, 4× M3 holes — per [mechanical.md](mechanical.md). Confirm
   against the real tray interior first.
3. **Placement:** 12 identical channel cells in rows; **inputs (`J_BIAS`+`J_SIPM`) on one
   long edge, `J_OUT` on the other** (signal flows across). Keep each front-end node compact.
4. **Net classes** apply automatically (`hv_bias` 0.6 mm clearance on `BIAS*`/`SIPM*`/`FE*`;
   `signal` 0.33 mm for `OUT*`; `power` 0.5 mm). Guard the front-end node.
5. **Route** — either the KiCad interactive router, or **autoroute with FreeRouting**:
   clean placement (no clearance/short DRC) → `export_dsn.py` (or GUI Specctra DSN export)
   → FreeRouting → `import_ses.py` (or GUI Specctra Session import). Full steps +
   FreeRouting download in [../docs/FREEROUTING.md](../docs/FREEROUTING.md).
6. Pour + stitch grounds (after routing). **DRC until 0 errors** (creepage is an error).

> Gotcha (from `reference/ets-breakout`): headless `ZONE_FILLER.Fill()` segfaults — fill
> zones as a separate pass / in the GUI. Run `kicad-cli pcb drc` as the gate.

---

## Track 7 — Fabrication & assembly

1. Generate fab outputs (a KiCad **job set** is easiest):
   ```
   "C:/Program Files/KiCad/10.0/bin/kicad-cli.exe" pcb export gerbers <pcb> -o fab/gerber/
   "C:/Program Files/KiCad/10.0/bin/kicad-cli.exe" pcb export drill   <pcb> -o fab/drill/
   "C:/Program Files/KiCad/10.0/bin/kicad-cli.exe" pcb export pos      <pcb> -o fab/pos.csv --format csv --units mm
   ```
2. Export the **fielded BOM** with the **Full** DNP set (already drafted in
   [bom/bom.md](bom/bom.md)); reconcile against the schematic export.
3. Order FR4/ENIG, 1.6 mm. Assemble per
   [../docs/fabrication/fabrication-guide.md](../docs/fabrication/fabrication-guide.md);
   bench bring-up + the Track 2 checklist in
   [../docs/hardware/circuit-design.md](../docs/hardware/circuit-design.md).

> `fab/`, `gerber/`, etc. are git-ignored — regenerate before ordering.

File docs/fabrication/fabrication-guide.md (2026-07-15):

# Fabrication and Assembly Guide

How to generate fab outputs, order the board, and assemble it — including the
**optional-population (DNP) variants** that are the defining feature of this design.

This board is a **single PCB** (12 channels on one board), unlike the multi-board
reference systems. Quantities below are per board.

---

## Generating fabrication files

Use the KiCad pipeline established by `ets-breakout` (KiCad 9/10 CLI + bundled Python):

1. **Open** `hardware/multi-channel-cremat-amplifier.kicad_pro` (the board is built and
   DRC-clean).
2. **DRC gate:** `kicad-cli pcb drc <pcb>` → must be **0 errors** (clearance, creepage,
   etc. — see [../hardware/pcb-design-rules.md](../hardware/pcb-design-rules.md)).
3. **Fill zones** as a *separate* pass on the saved file (headless in-memory zone fill
   segfaults — a documented gotcha in both reference projects).
4. **Export** gerbers + Excellon drill + placement CSV, and generate the BOM CSV:
   ```
   kicad-cli pcb export gerbers <pcb> -o pcbfab/gerber/
   kicad-cli pcb export drill   <pcb> -o pcbfab/drill/
   kicad-cli pcb export pos     <pcb> -o assembly/positions.csv --format csv --units mm
   #  + project BOM export (with MPN/VPN and DNP column)
   ```
5. A KiCad **job set** (`fab-files.kicad_jobset`) is the recommended way to automate 2–4,
   as the reference projects do.

> `pcbfab/`, `assembly/`, and `**/fab/` are git-ignored — **regenerate from source before
> every order**.

---

## PCB specifications (request from fab)

| Parameter | Value |
|---|---|
| Layers | **4** (finalized — F.Cu / In1 GND / In2 −VDC / B.Cu +VDC), ordered from JLCPCB |
| Material | FR4 (1 oz outer copper) |
| Thickness | 1.6 mm |
| Min track / clearance | per net class; **HV bias clearance set by bias voltage** |
| Surface finish | ENIG (recommended for fine-pitch + low-leakage front-end) |
| Solder mask / silk | both sides |
| Controlled impedance | only if `OUT` is run as 50 Ω — then declare it |

For low-current / low-noise front-ends, the reference docs suggest a low-absorption
substrate; FR4 with ENIG is the practical default here.

---

## Assembly — choose the build variant first

Decide the configuration **before** assembly; it sets the DNP list
([../hardware/bom.md](../hardware/bom.md)):

| Build | Bias filter | CR-210 |
|---|---|---|
| Full | fitted | fitted |
| No-BLR | fitted | bypassed |
| External-bias | bypassed | either |
| Reference-equivalent | bypassed | bypassed |

### The one assembly invariant
For each optional block, populate **either** the block **or** its 0R bypass — **never
both**:

- Bias filter: `Rf1`,`Rf2`,`Cf` **xor** `JP_Rf1`,`JP_Rf2`
- CR-210: `U_BLR` **xor** `JP_BLR`
- Output buffer (THS3491): the buffer **xor** its 0R bypass — the **default build fits the bypass** (THS3491 DNP)

Populating both shorts out / parallels the block. Check this per channel after placement.

### Order of assembly
1. **SMD first** (reflow / stencil): 0805 R/C, 0R jumpers, op-amps. Apply the DNP list so
   the wrong path isn't placed.
2. **Trimpots, then the Cremat module sockets** (Samtec SS-108-TT-2 SIP-8, **36/board** — 3
   socket strips per module site × 12) — through-hole, hand-soldered. Then **plug in** the
   Cremat modules (CR-112, CR-200-1µs, and CR-210 if fitted) — the modules are **never
   soldered**; observe **pin-1** (white dot on Cremat modules).
3. **Coax jacks and connectors** last (align to board edge).

### HV / SiPM cautions during bring-up
- The `BIAS_IN`, filter, front-end, and `SIPM` nets reach the **full bias voltage**.
  Ramp bias from 0 V; never hot-plug detectors.
- `Cc` (and `Cf`) must be the **voltage-rated** parts from the BOM — verify before
  powering.

---

## Post-assembly checks

1. **Continuity / isolation:** `+VDC`–`GND`, `-VDC`–`GND`, and `BIAS_IN`–`GND` not shorted.
2. **Jumper audit:** confirm exactly one path populated for every optional block, all 12
   channels.
3. **Power-only bring-up:** apply ±Vs (no bias, no detector); confirm module quiescent
   currents are sane and outputs sit near baseline.
4. **Bias bring-up:** with a detector or a test pulse, ramp `BIAS_IN`; verify the
   front-end node biases and a pulse appears at `OUT`.
5. **Per-channel functional test:** inject charge (test-pulse cap into the CSP input) and
   confirm shaped pulses on all 12 `OUT` jacks; trim the P/Z per channel (there is no per-channel gain trim).

---

## Storage / handling

- SiPMs and the analog front-end are ESD-sensitive — grounded strap + mat.
- Store assembled boards in anti-static bags; keep away from the HV supply when not in
  controlled use.

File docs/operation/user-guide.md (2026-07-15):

# User and Operation Guide

How to power, bias, and operate the 12-channel Cremat amplifier, and how to choose the
populate/bypass options. This is a **passive (always-on) analog board** — there is no
firmware, no commands, no channel selection. All 12 channels amplify continuously.

---

## What you connect

All per-channel jacks are **MCX** (TE Linx `CONMCX013`). Each channel has **four**:

| Connector | Qty | Connect to |
|---|---|---|
| `BIAS_IN` (per channel) | 12 | Detector bias supply (HV, ≤ 70 V), one feed per channel |
| `SIPM` (per channel) | 12 | One detector each (coax). Carries **DC bias + signal** on the same line. |
| `TEST` (per channel) | 12 | Test-pulse injection input (coax) for per-channel calibration; leave open in normal use. |
| `OUT` (per channel) | 12 | DAQ / digitizer / scope input (50 Ω, coax). |
| `J_PWR` — power in (±Vs, GND) | 1 | Dual analog supply (Cremat-style, typically ±12 V — confirm module ratings). 3-pos 5.08 mm screw terminal. |
| `J_DAISY` — daisy-chain out (±Vs, GND) | 1 | Passes the raw ±Vs rails on to the next 1U box. 3-pos 5.08 mm screw terminal. |

**`BIAS_IN` is per-channel**, so channels can be biased independently. To run them all at
one voltage, fan a single bias supply out to the 12 `BIAS_IN` jacks (external splitter /
daisy-chain). The board does not distribute bias internally.

**Multiple boards daisy-chain box-to-box:** each board lives in its own Hammond
RM1U1908VBK 1U case; `J_DAISY` passes the raw ±Vs rails from one box on to the next
board's `J_PWR`.

---

## Choosing the configuration (set at assembly)

The board is built in one fixed configuration (see
[../hardware/bom.md](../hardware/bom.md)). Pick based on your setup:

| If you… | Bias filter | CR-210 |
|---|---|---|
| bias SiPMs from a noisy supply | **fit** the RC+R filter | — |
| have a clean external bias / external bias-tee | **bypass** the filter (0R) | — |
| run at medium/high count rate, care about resolution | — | **fit** the CR-210 |
| run at low rate or want minimum latency | — | **bypass** the CR-210 (0R) |

You cannot change these at runtime; they are populate/DNP choices on the PCB.

---

## Power-up sequence

1. Confirm the build's jumper configuration matches your intended use (label the board).
2. Apply **±Vs** first (analog supply). The amplifier chain powers up.
3. Ramp **`BIAS_IN`** from **0 V** up to the detector operating voltage **gradually** —
   the on-board filter (if fitted) adds an RC settling time; allow it to settle.
4. Observe `OUT` on a scope: with a detector and light (or dark counts), you should see
   shaped Gaussian pulses.

## Power-down sequence

1. Ramp **`BIAS_IN`** to **0 V** first.
2. Then remove **±Vs**.
3. Only then disconnect detectors or output cables.

> **Never** connect/disconnect a detector while `BIAS_IN` is live.

---

## Per-channel signal path (what happens to a detector pulse)

```
detector charge ─► SiPM (DC-biased via filter) ─► Cc (AC) ─► CR-11X CSP ─► CR-200-X shaper
                                                            ─► [CR-210 BLR] ─► buffer ─► OUT
```

- The **filtered DC bias** holds the SiPM at operating voltage (DC path to `SIPM`).
- The SiPM's **current pulse** passes through `Cc` into the charge-sensitive preamp (AC
  path) — the DC bias is blocked from the amplifier.
- The shaper produces a Gaussian pulse; if the **CR-210** is fitted it holds the baseline
  at ground (better at high rate); the output stage drives it into 50 Ω coax at `OUT` — the
  shaper directly via the 49.9 Ω back-termination by default, or the optional **THS3491**
  buffer if that channel is populated.

---

## Tuning

- **Pole-zero (P/Z):** each channel has a P/Z trimpot on the CR-200-X. With a test pulse
  (or detector pulses) on the scope, adjust until the shaped pulse returns cleanly to
  baseline with no undershoot/overshoot.
- **Output buffer:** there are **no gain/offset trims**. The per-channel output buffer is a
  TI **THS3491** CFA, fitted as a **populate option (DNP by default)**; in the default build a
  0R jumper bypasses it and the shaper drives the 49.9 Ω back-termination directly.
- **Shaping time** is fixed by the CR-200-**X** part installed (chosen at order time).

---

## Troubleshooting

| Symptom | Likely cause | Action |
|---|---|---|
| No pulses on a channel | bias not reaching detector | check `BIAS_IN`, and that the filter path or its 0R bypass is populated (not neither) |
| Output railed / large DC offset | `Cc` not blocking (leaky / unpopulated) | verify `Cc` populated & rated for the bias voltage |
| Baseline shifts with rate | CR-210 bypassed | rebuild with CR-210 fitted, or accept for low-rate use |
| Excess noise on all channels | bias-supply noise / filter bypassed | fit the bias filter; check `GND` integrity |
| One channel oscillates | P/Z mis-trim or layout | re-trim P/Z; inspect that channel's front-end |
| Both block and its 0R fitted | assembly error | remove one — block and bypass are mutually exclusive ([bom.md](../hardware/bom.md)) |

---

## Safety

1. **High voltage:** `BIAS_IN` and the `SIPM` lines carry the bias voltage (tens of volts
   for SiPMs, possibly more). Ramp down before touching detector cabling. Follow lab HV
   practice.
2. **ESD:** SiPMs and the front-end are ESD-sensitive — grounded strap + mat.
3. **Per-channel bias:** each channel has its own `BIAS_IN`. If you fan one supply out to
   all 12, a fault on one line still pulls on the common external supply — keep the bias
   filter fitted (its series R limits fault current) and add per-feed protection if needed.

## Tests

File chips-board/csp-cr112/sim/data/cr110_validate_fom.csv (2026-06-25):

metric | value
peak_amplitude_mV | -710.867
charge_gain_mV_per_pC | -1421.73
rise_time_10_90_ns | 7.17759
decay_tau_us | 140.497
peak_time_us | 1.0734
Q_injected_pC | 0.5

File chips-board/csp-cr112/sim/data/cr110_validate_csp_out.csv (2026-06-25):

time_s | csp_out_V
0.000000000000000000e+00 | 0.000000000000000000e+00
5.036553600023672600e-08 | 0.000000000000000000e+00
1.015655360002393484e-07 | 0.000000000000000000e+00
1.527655360002431950e-07 | 0.000000000000000000e+00
2.039655360002470416e-07 | 0.000000000000000000e+00
2.551655360002508617e-07 | 0.000000000000000000e+00
3.063655360002547083e-07 | 0.000000000000000000e+00
3.575655360002585549e-07 | 0.000000000000000000e+00
4.087655360002624015e-07 | 0.000000000000000000e+00
4.599655360002662481e-07 | 0.000000000000000000e+00
5.111655360002700947e-07 | 0.000000000000000000e+00
5.623655360002739413e-07 | 0.000000000000000000e+00
6.135655360002777879e-07 | 0.000000000000000000e+00
6.647655360002816345e-07 | 0.000000000000000000e+00
7.159655360002854811e-07 | 0.000000000000000000e+00
7.671655360002893277e-07 | 0.000000000000000000e+00
8.183655360002931743e-07 | 0.000000000000000000e+00
8.695655360002970209e-07 | 0.000000000000000000e+00
9.207655360003008675e-07 | 0.000000000000000000e+00
9.719655360002660682e-07 | 0.000000000000000000e+00
9.999500000000000569e-07 | 0.000000000000000000e+00
9.999524206555443622e-07 | -4.055382060979412229e-13
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

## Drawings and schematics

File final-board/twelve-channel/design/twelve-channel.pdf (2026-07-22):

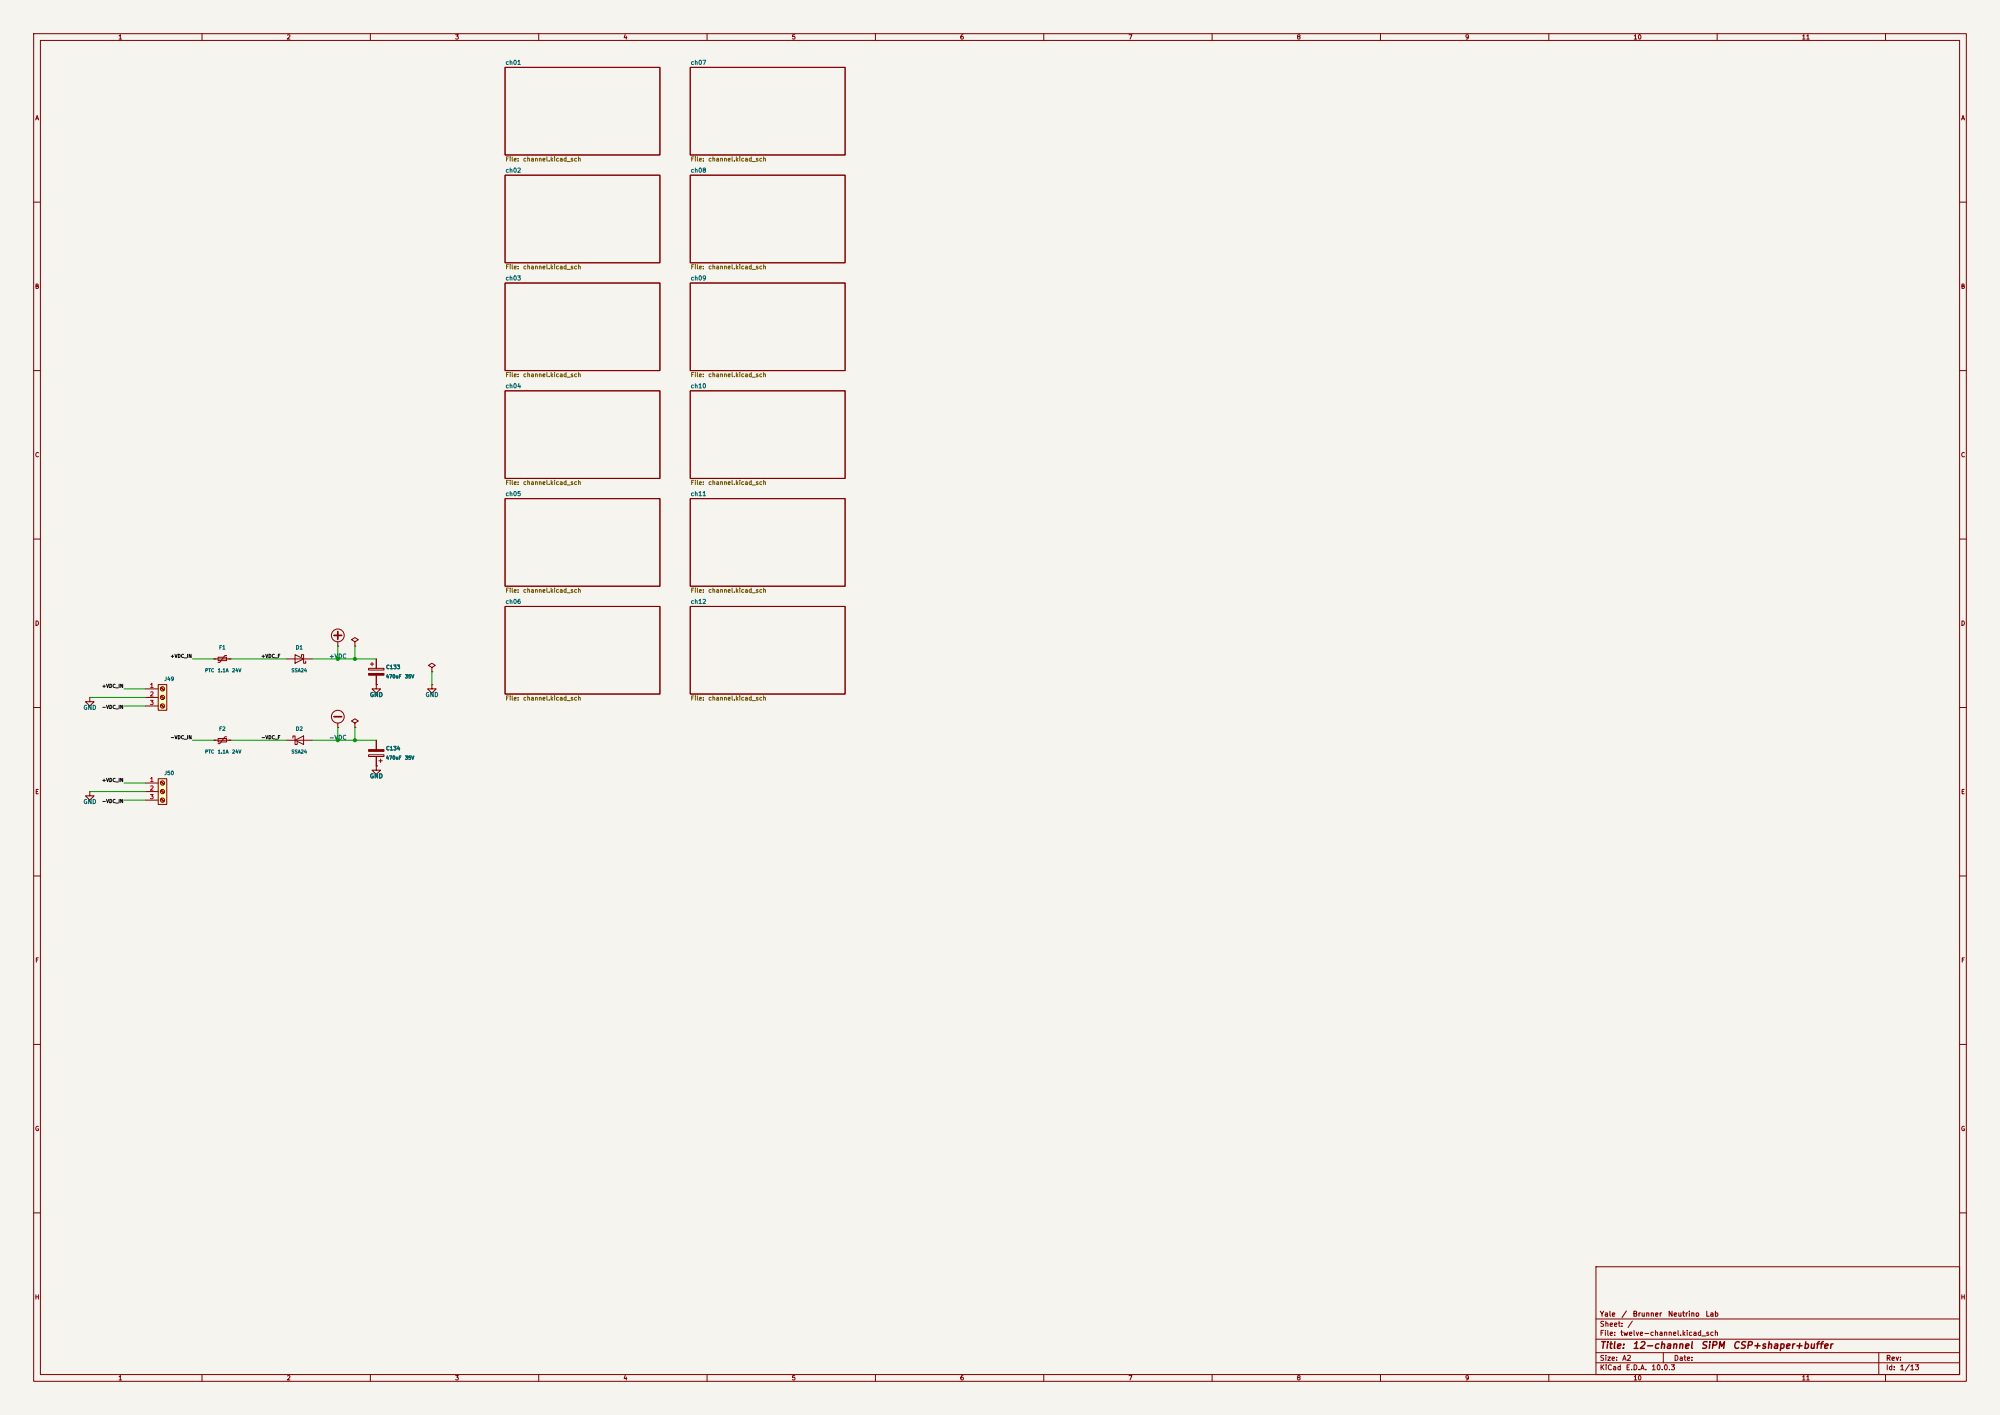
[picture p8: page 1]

Yale / Brunner Neutrino Lab
Sheet: /
File: twelve-channel.kicad_sch
Title: 12-channel SiPM CSP+shaper+buffer

Size: A2 | Rev:
KiCad E.D.A. 10.0.3 | Id: 1/13

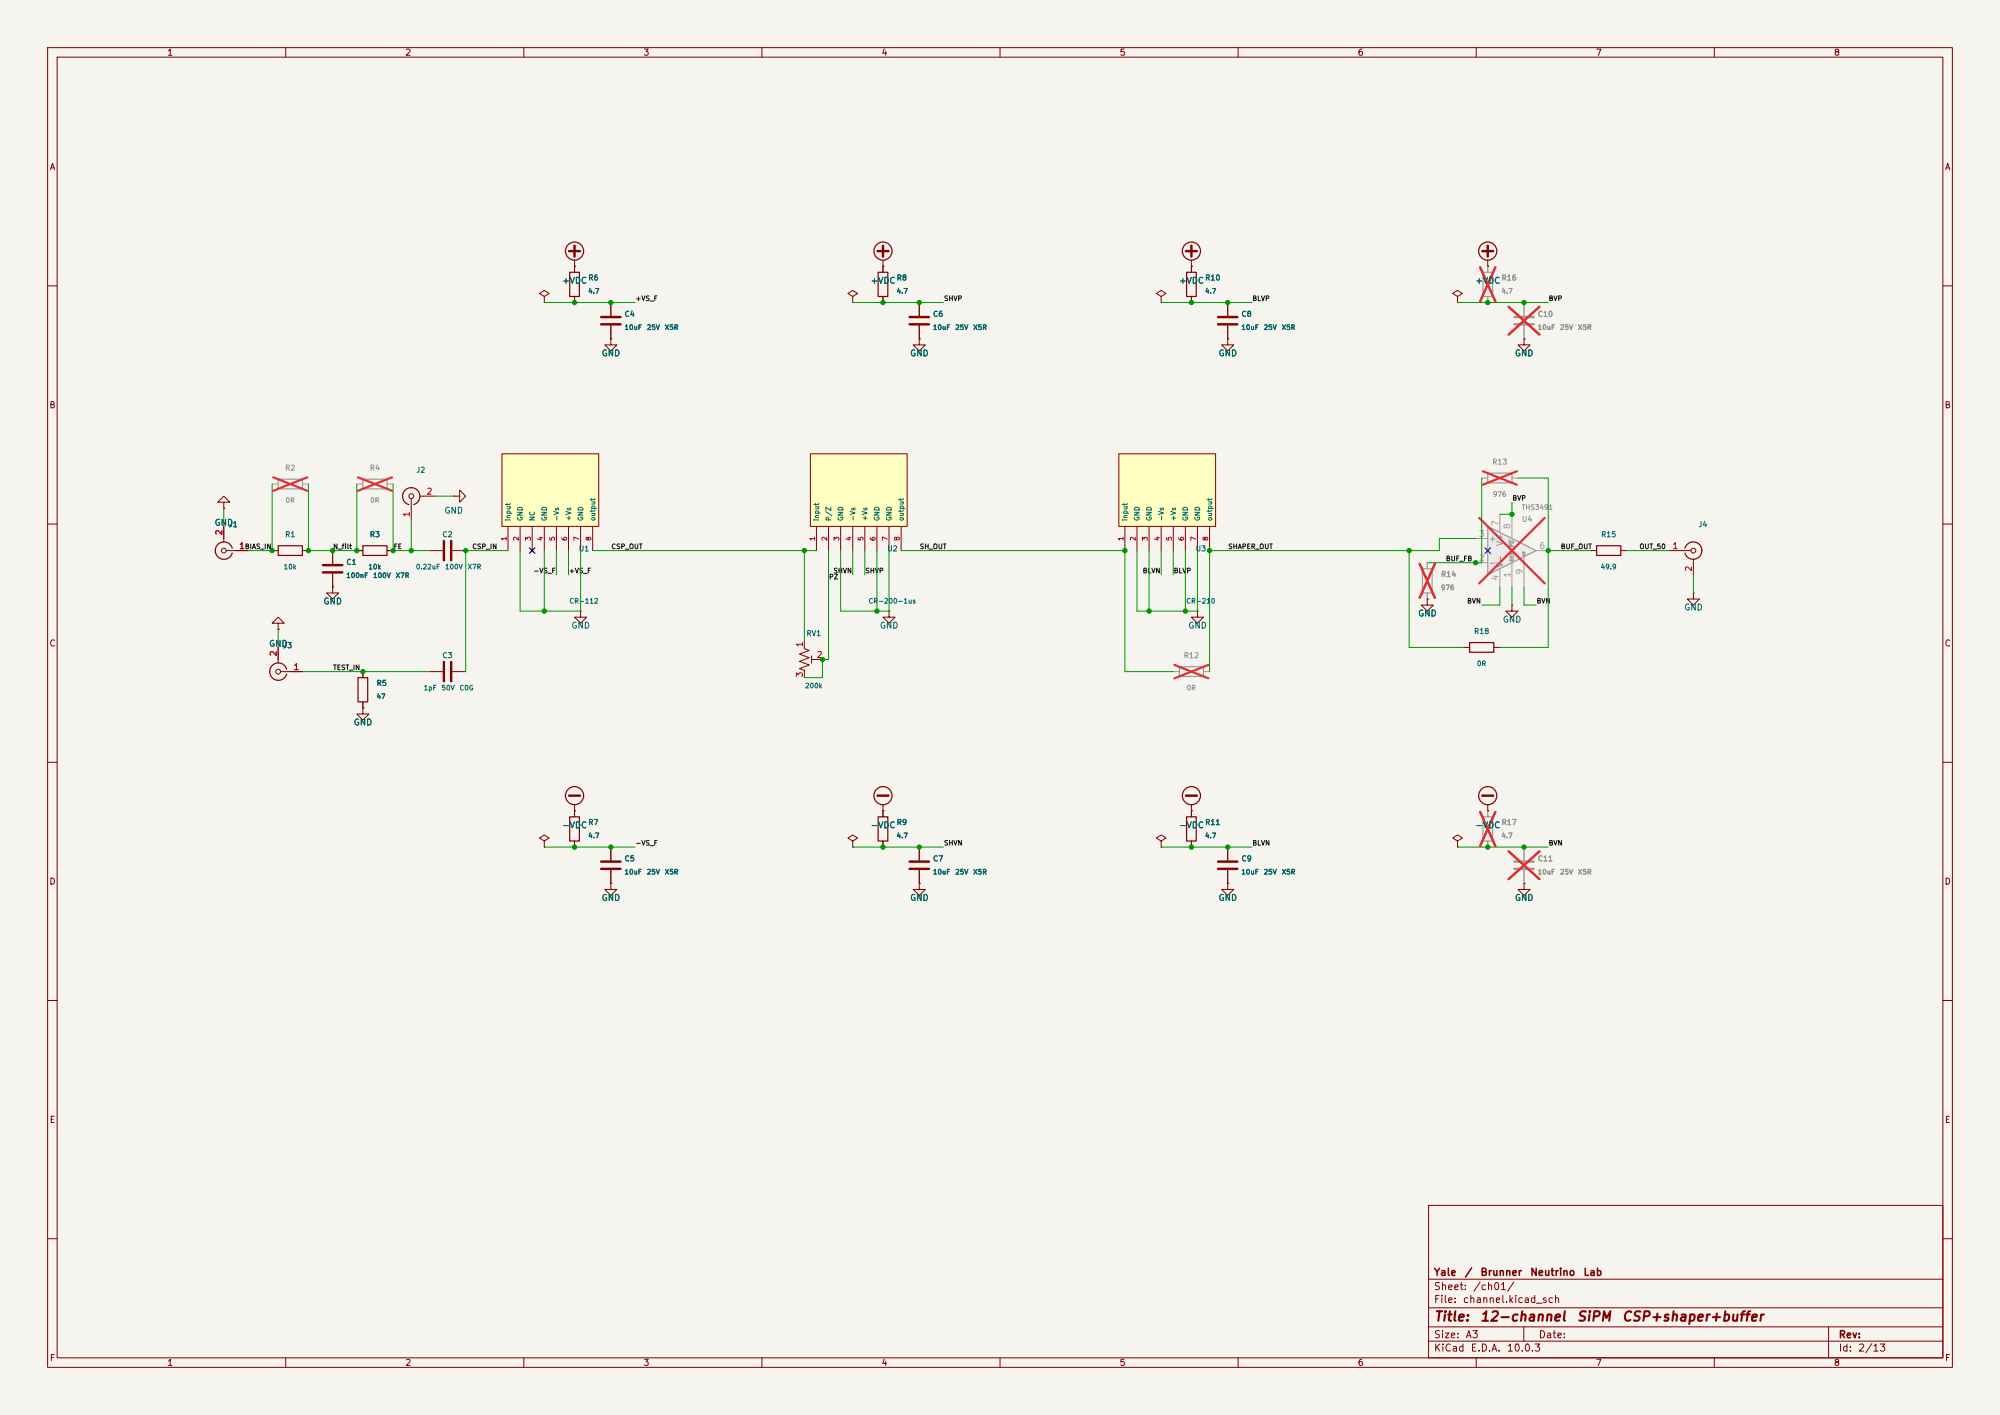
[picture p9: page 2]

Yale / Brunner Neutrino Lab
Sheet: /ch01/
File: channel.kicad_sch

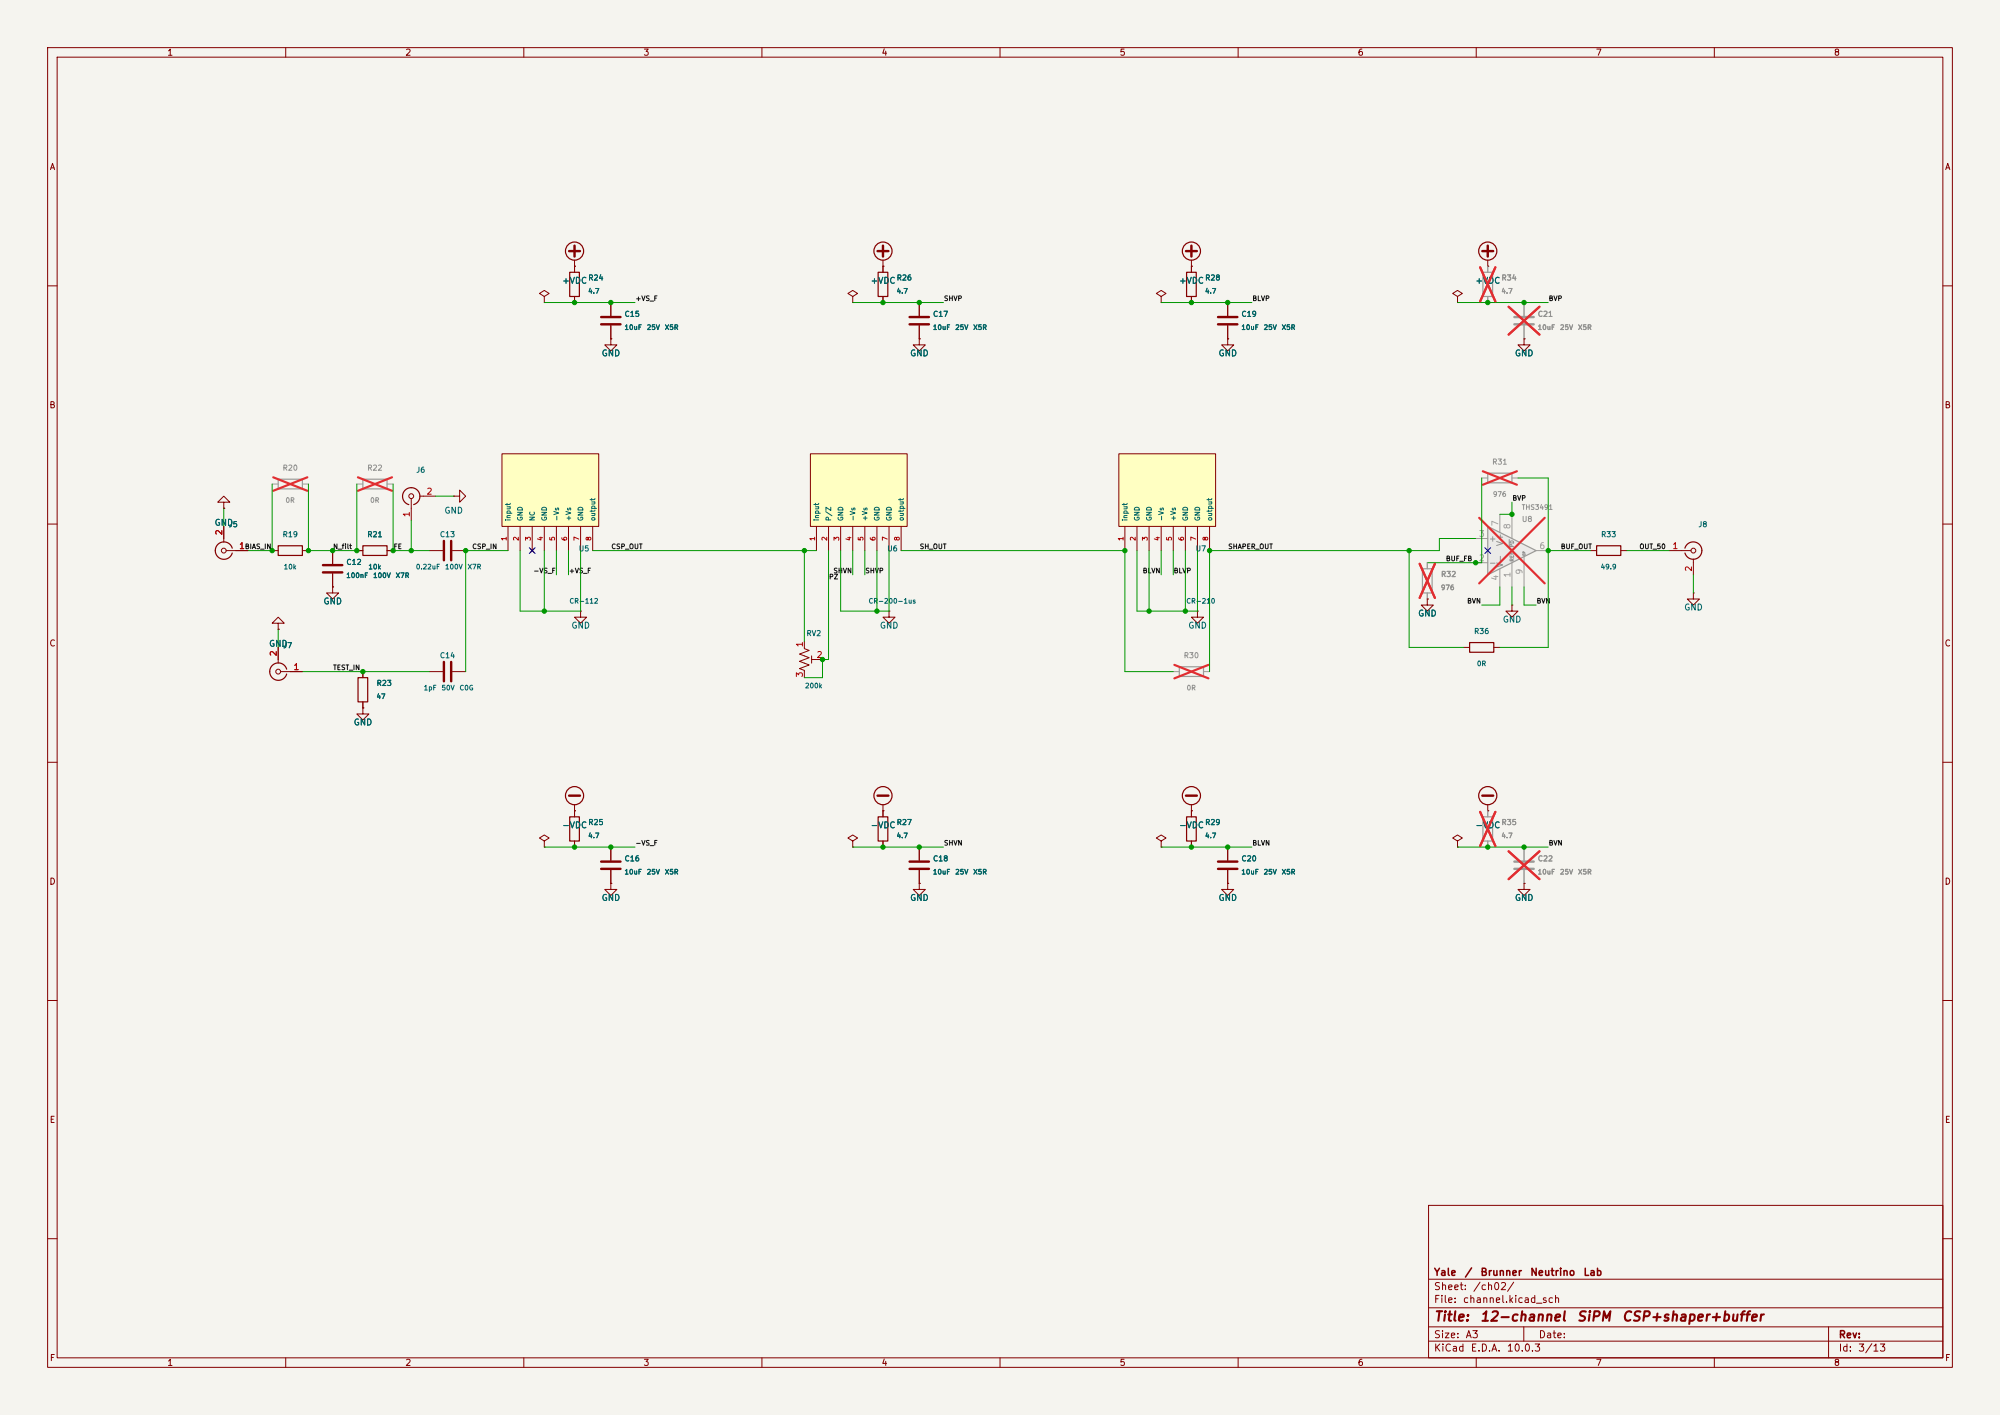
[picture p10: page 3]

Yale / Brunner Neutrino Lab
Sheet: /ch02/

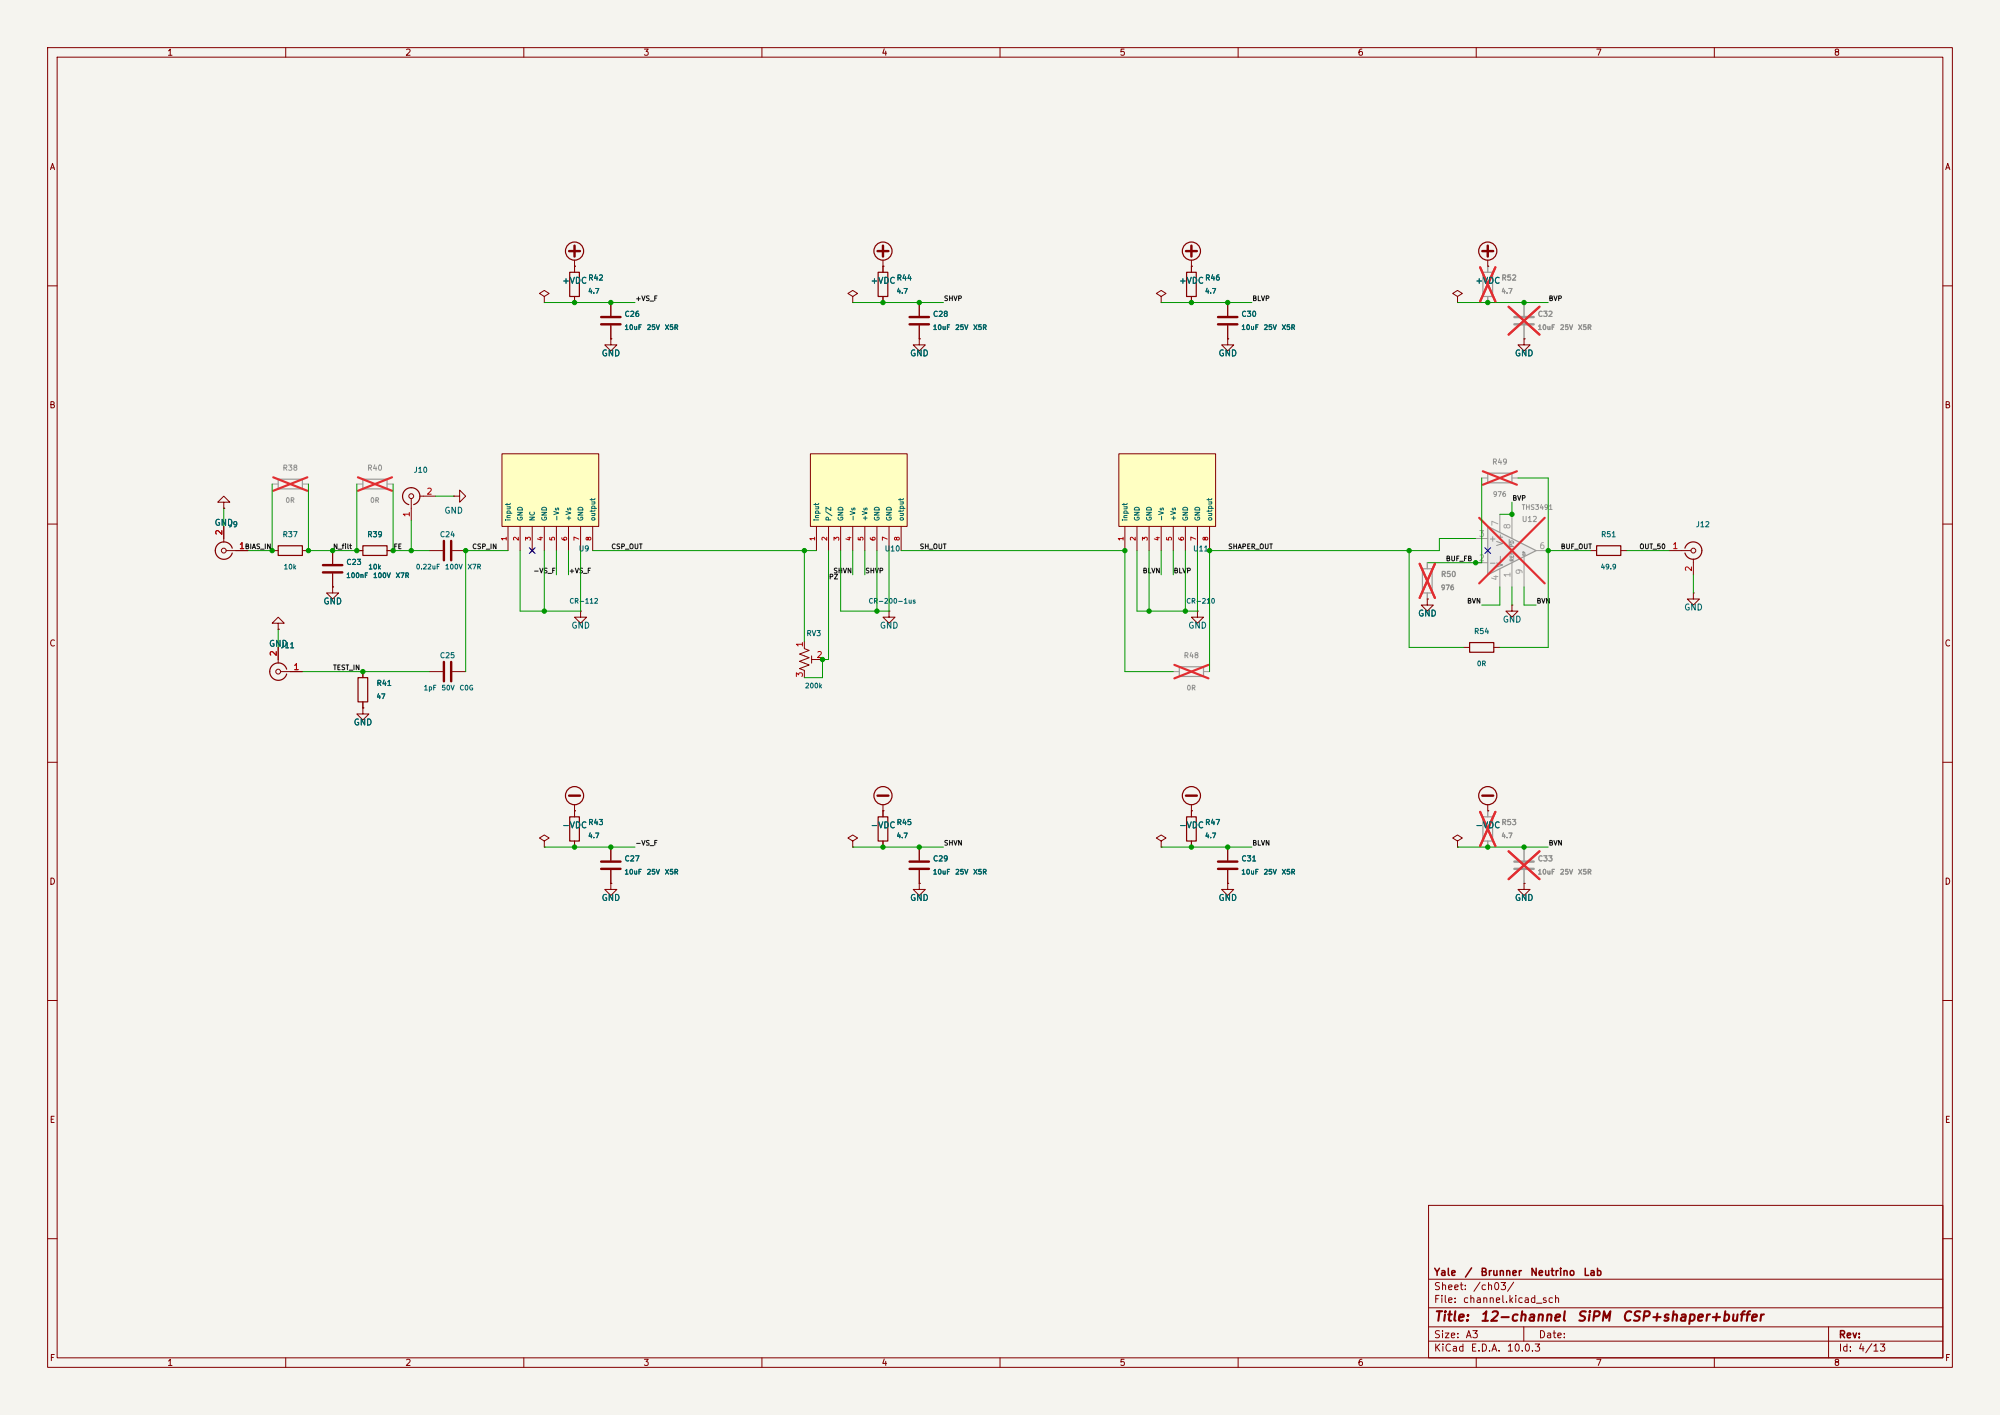
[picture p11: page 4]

Yale / Brunner Neutrino Lab
Sheet: /ch03/

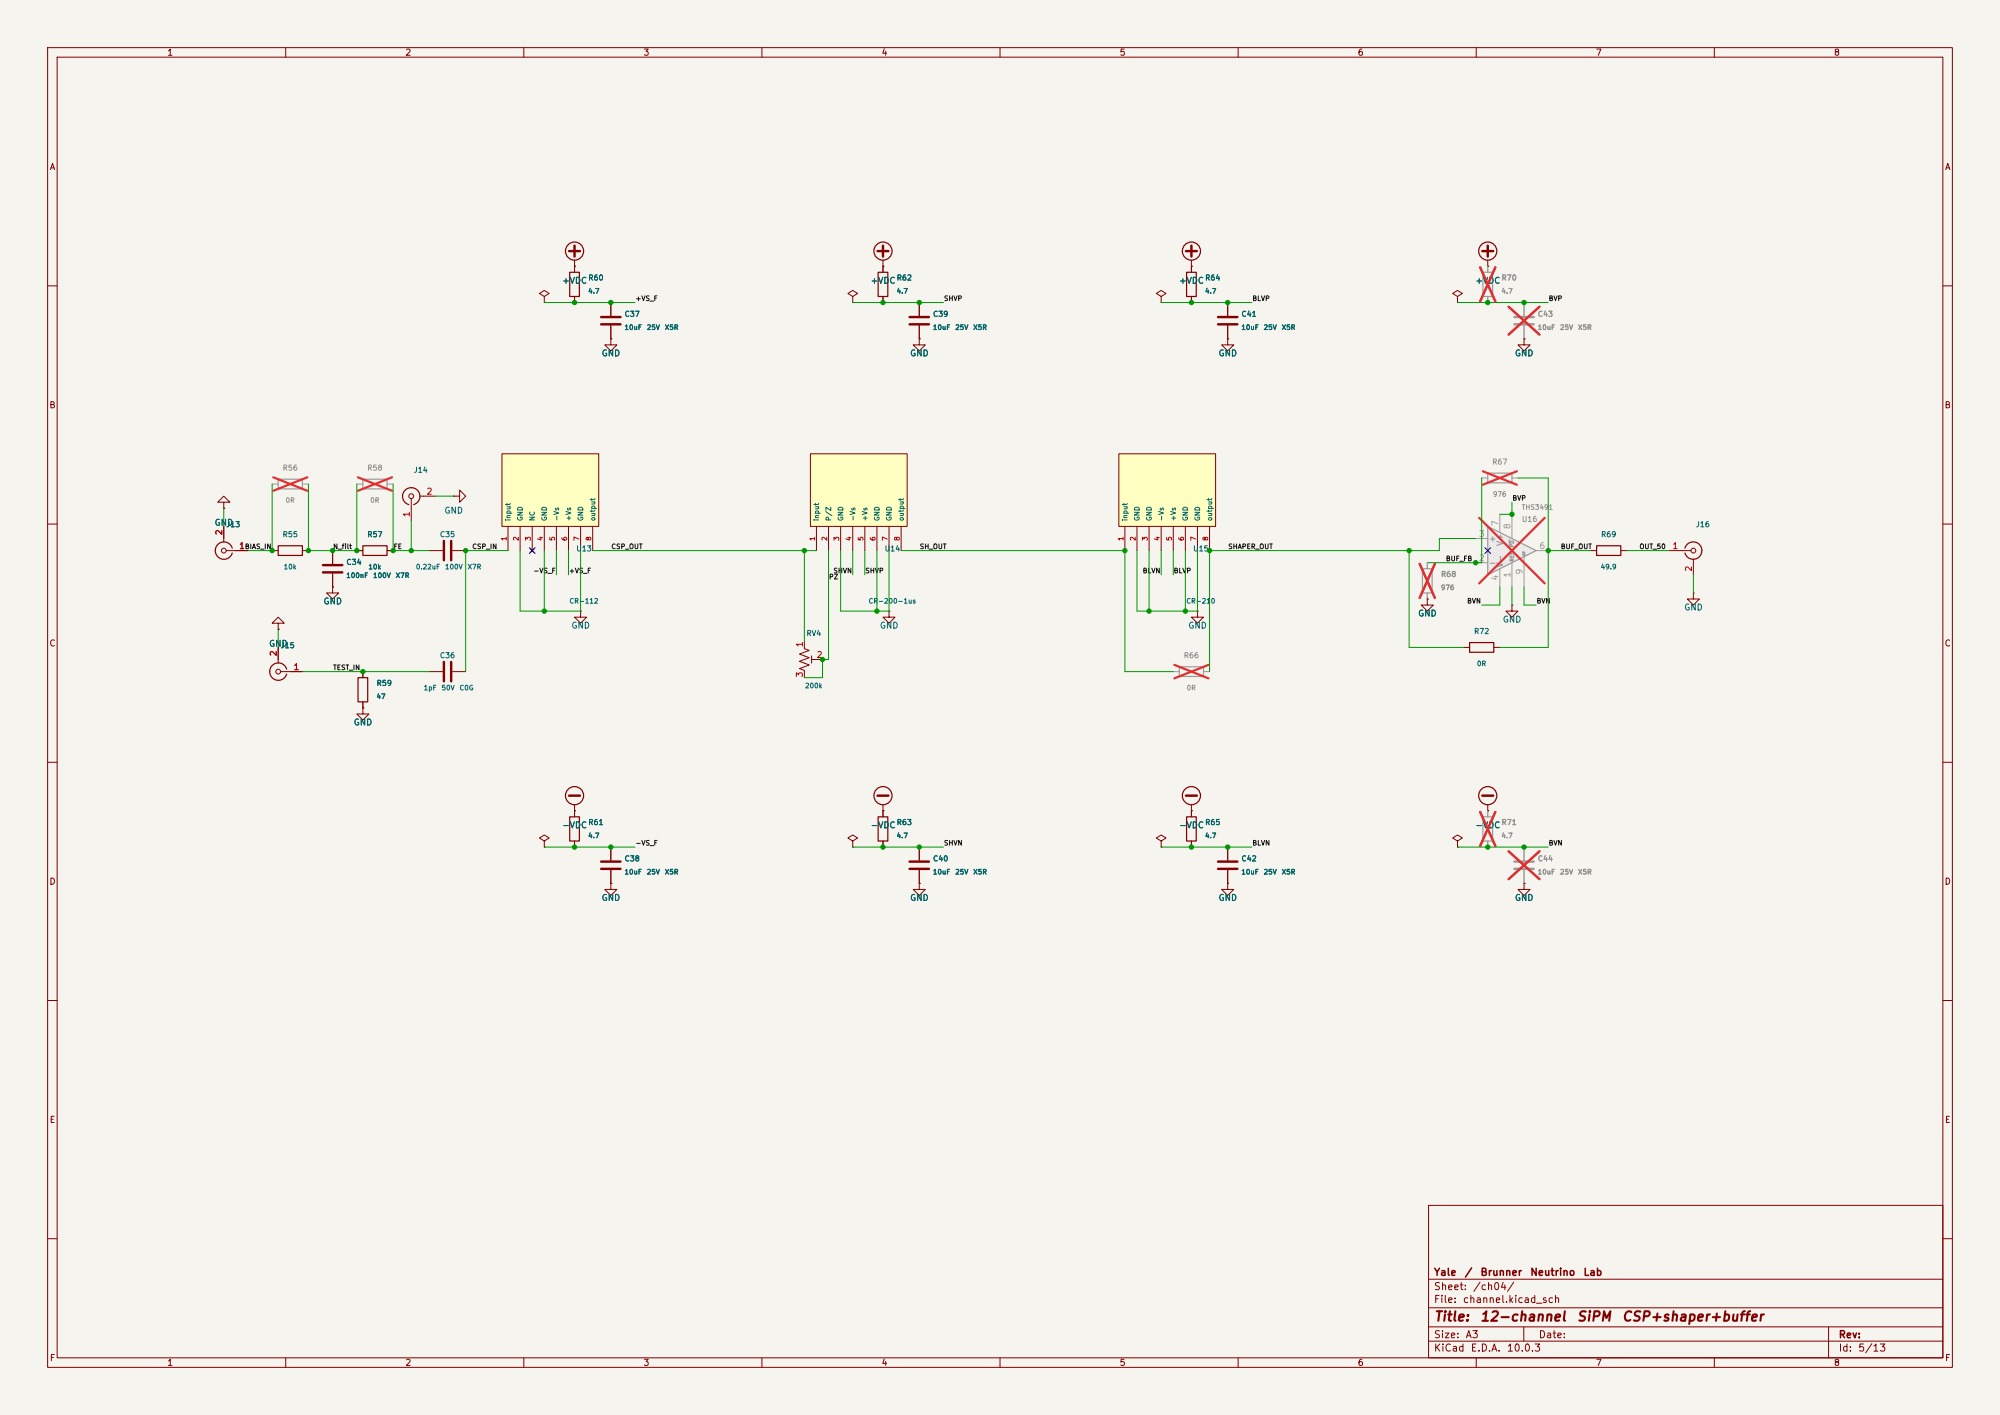
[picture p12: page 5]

Yale / Brunner Neutrino Lab
Sheet: /ch04/

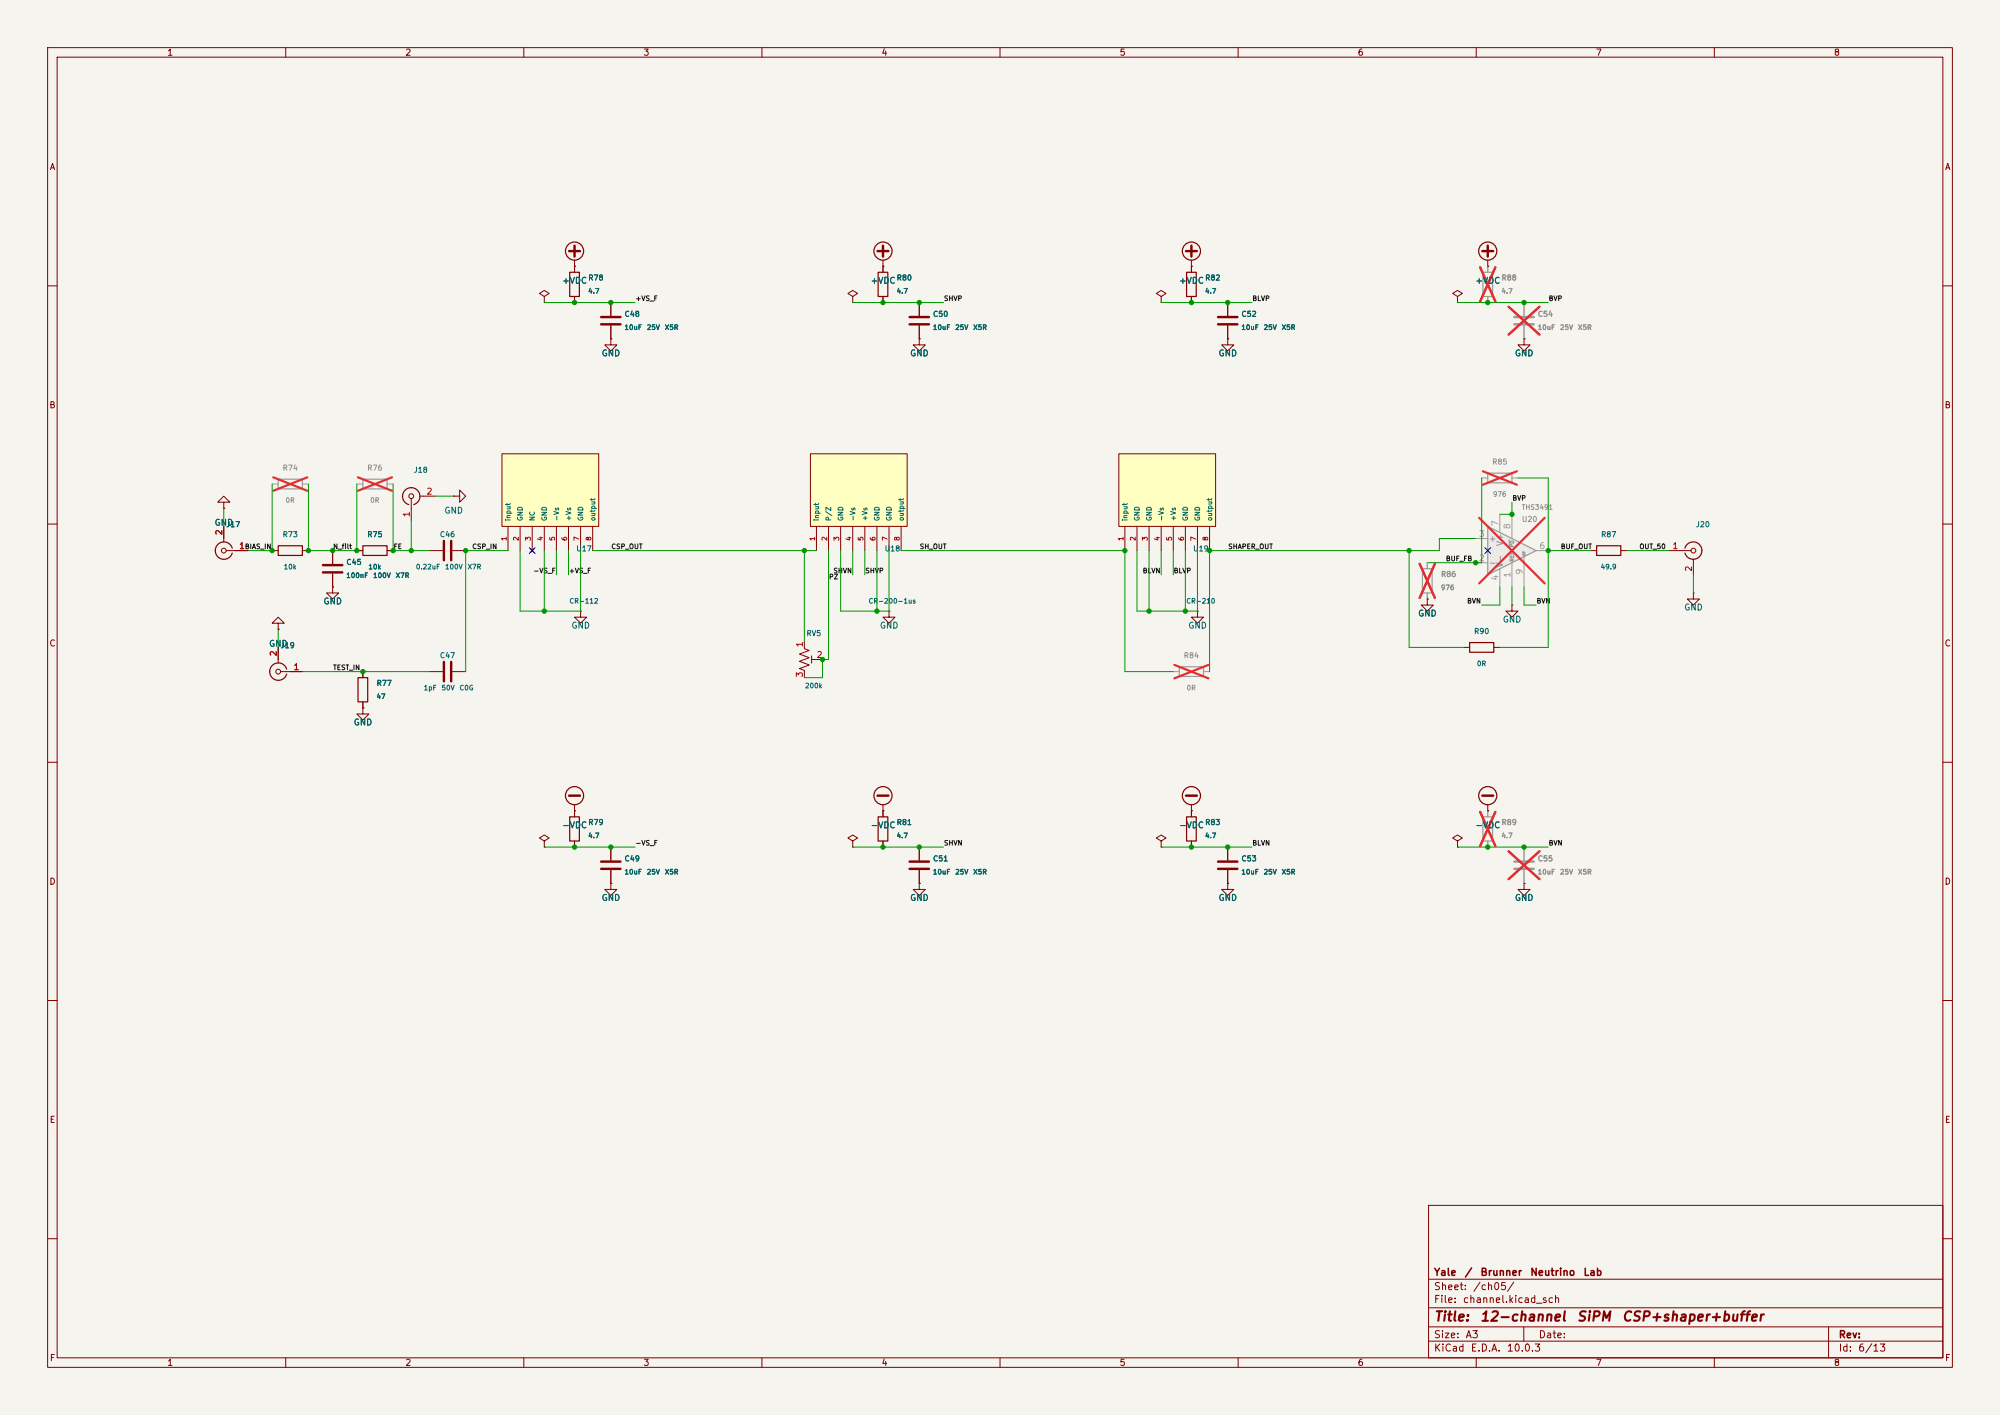
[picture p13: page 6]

Yale / Brunner Neutrino Lab
Sheet: /ch05/

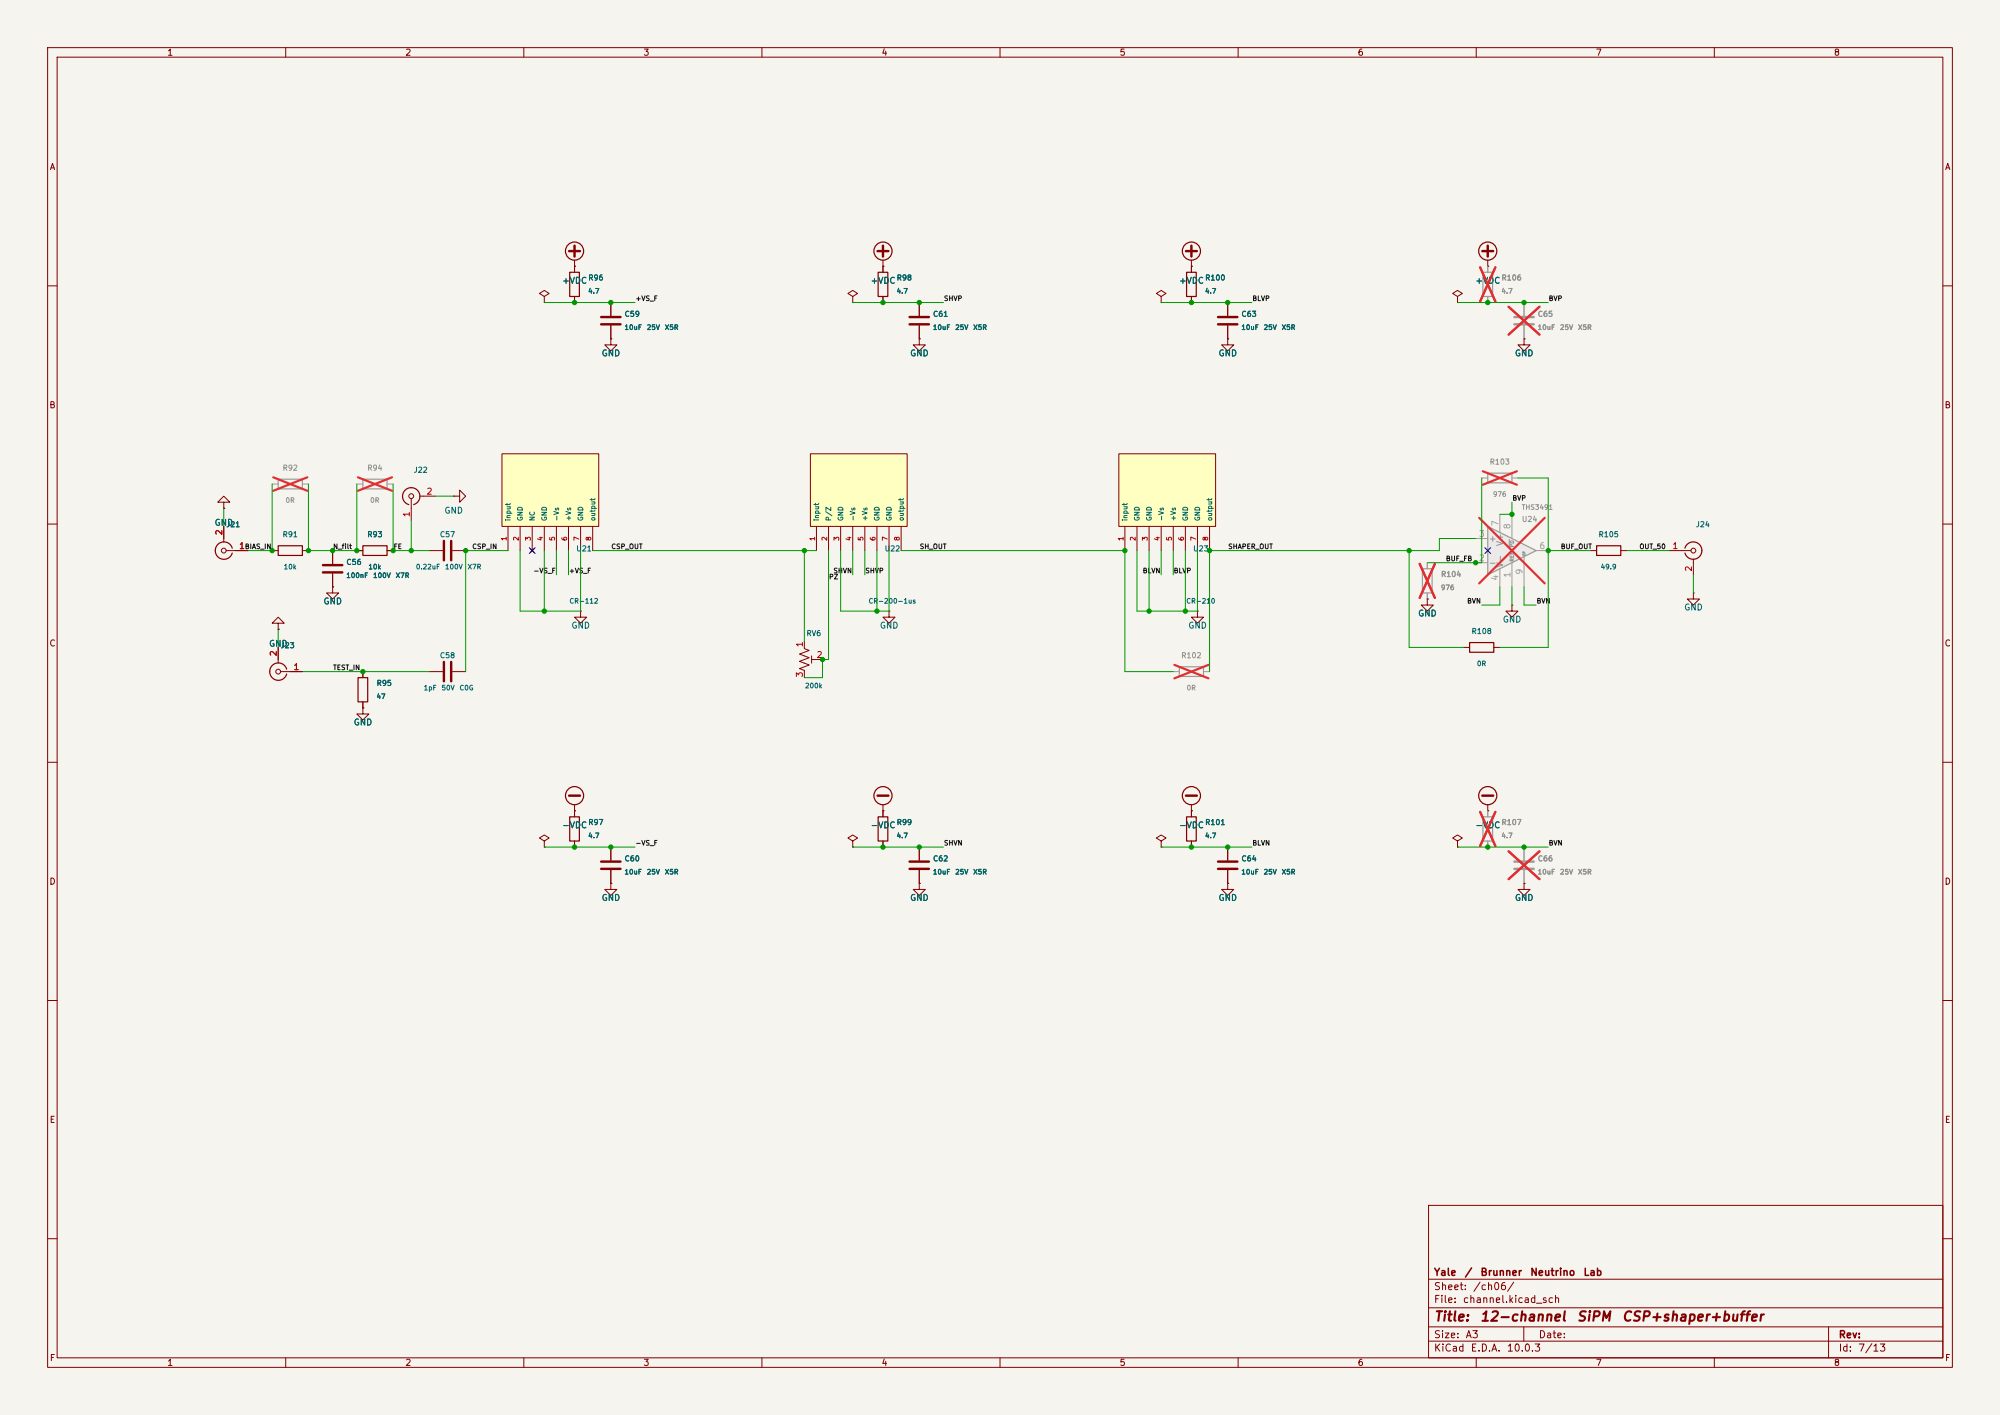
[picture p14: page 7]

Yale / Brunner Neutrino Lab
Sheet: /ch06/

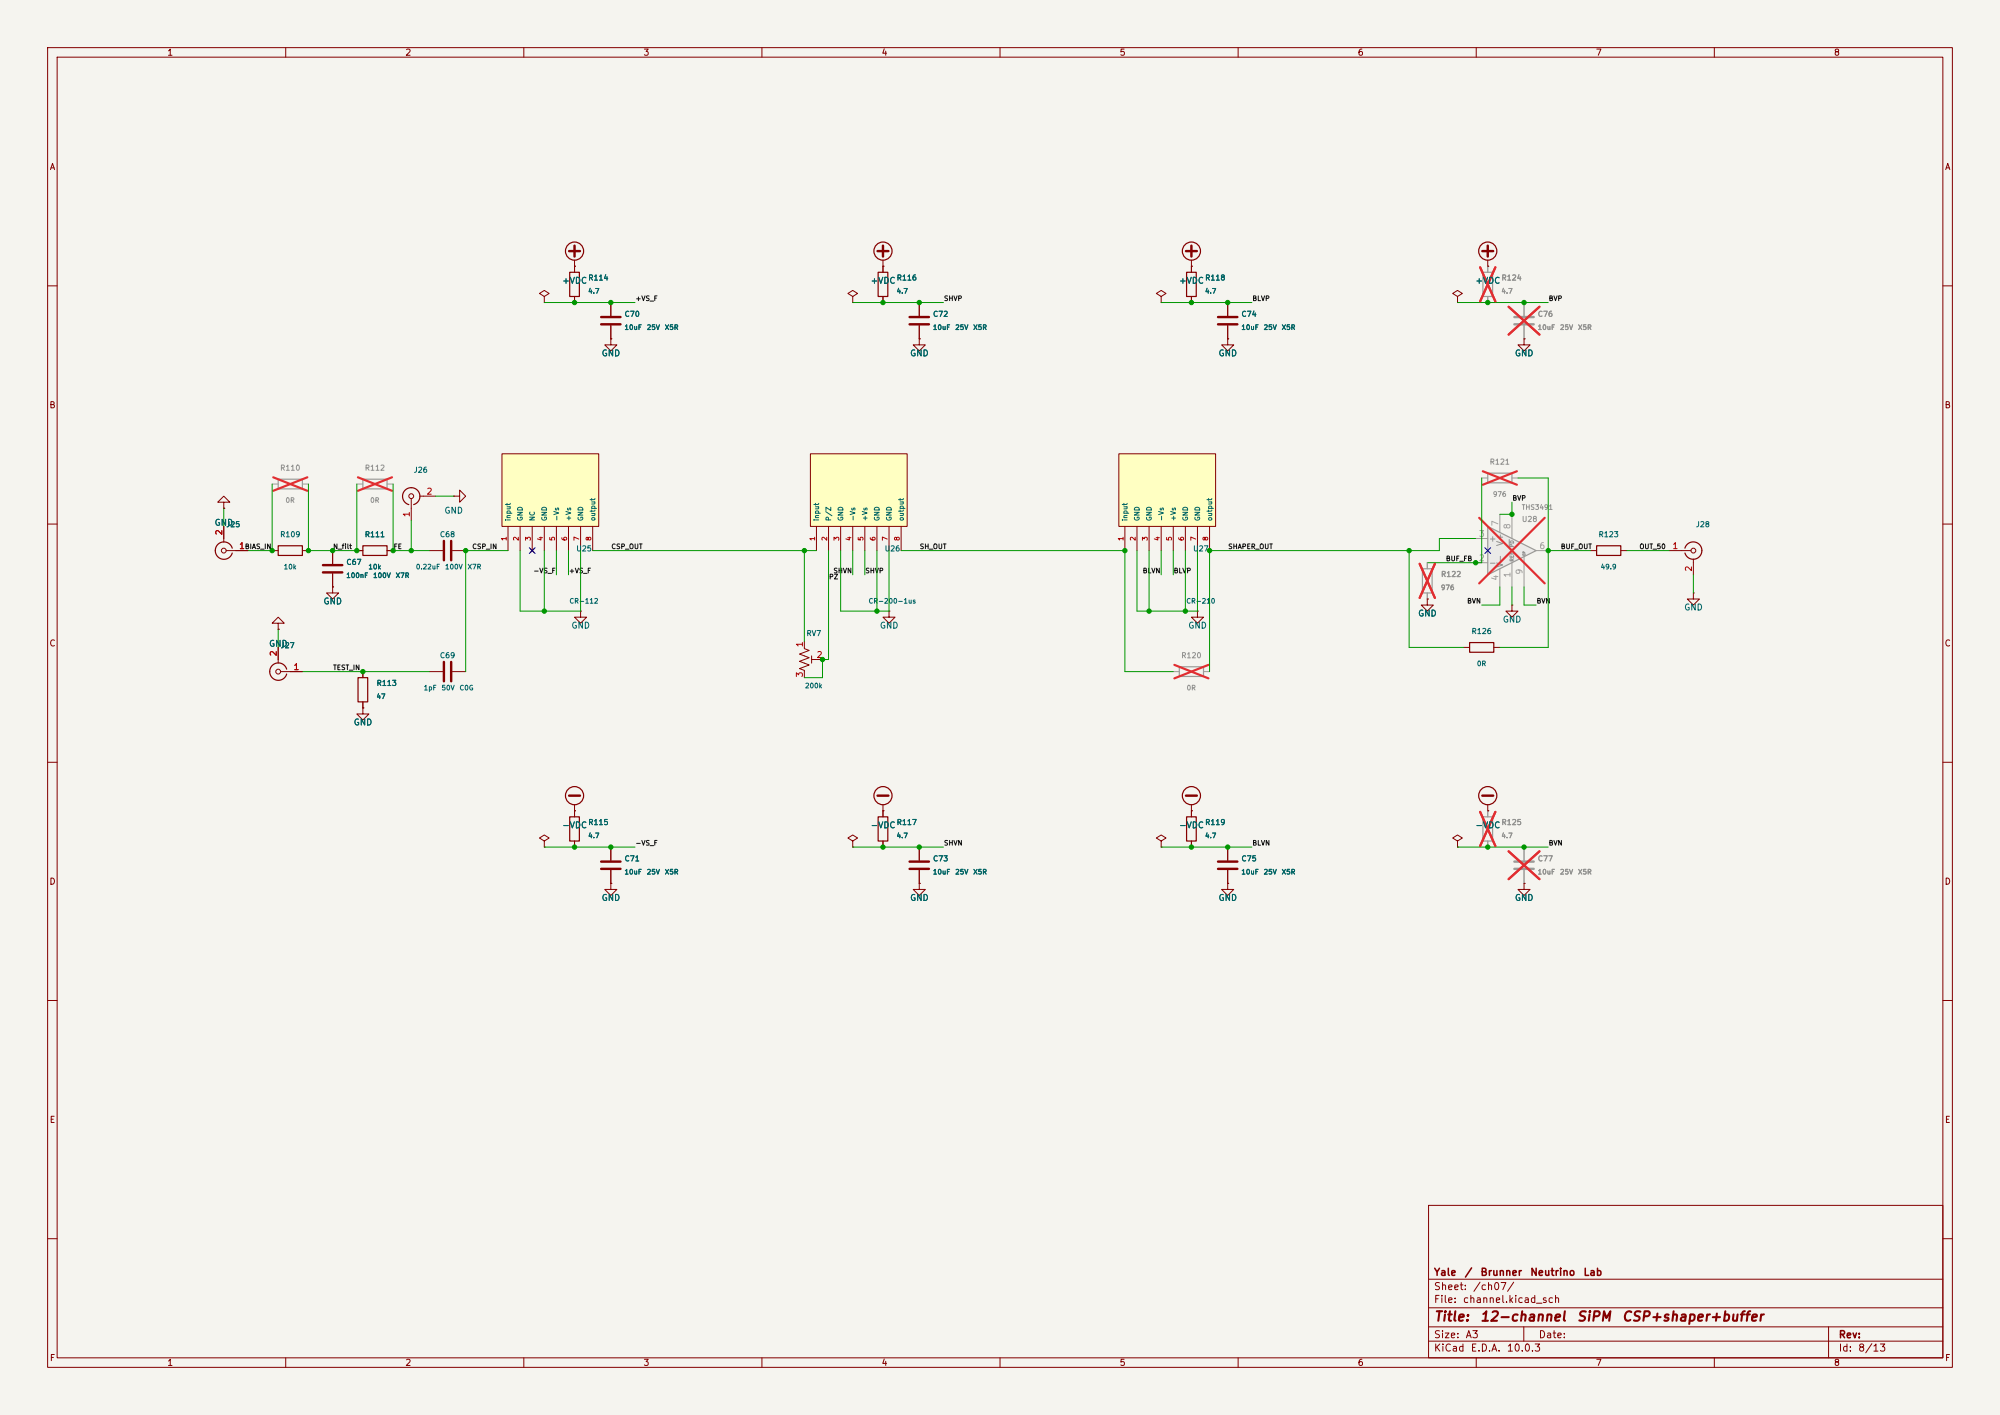
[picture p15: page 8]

Yale / Brunner Neutrino Lab
Sheet: /ch07/

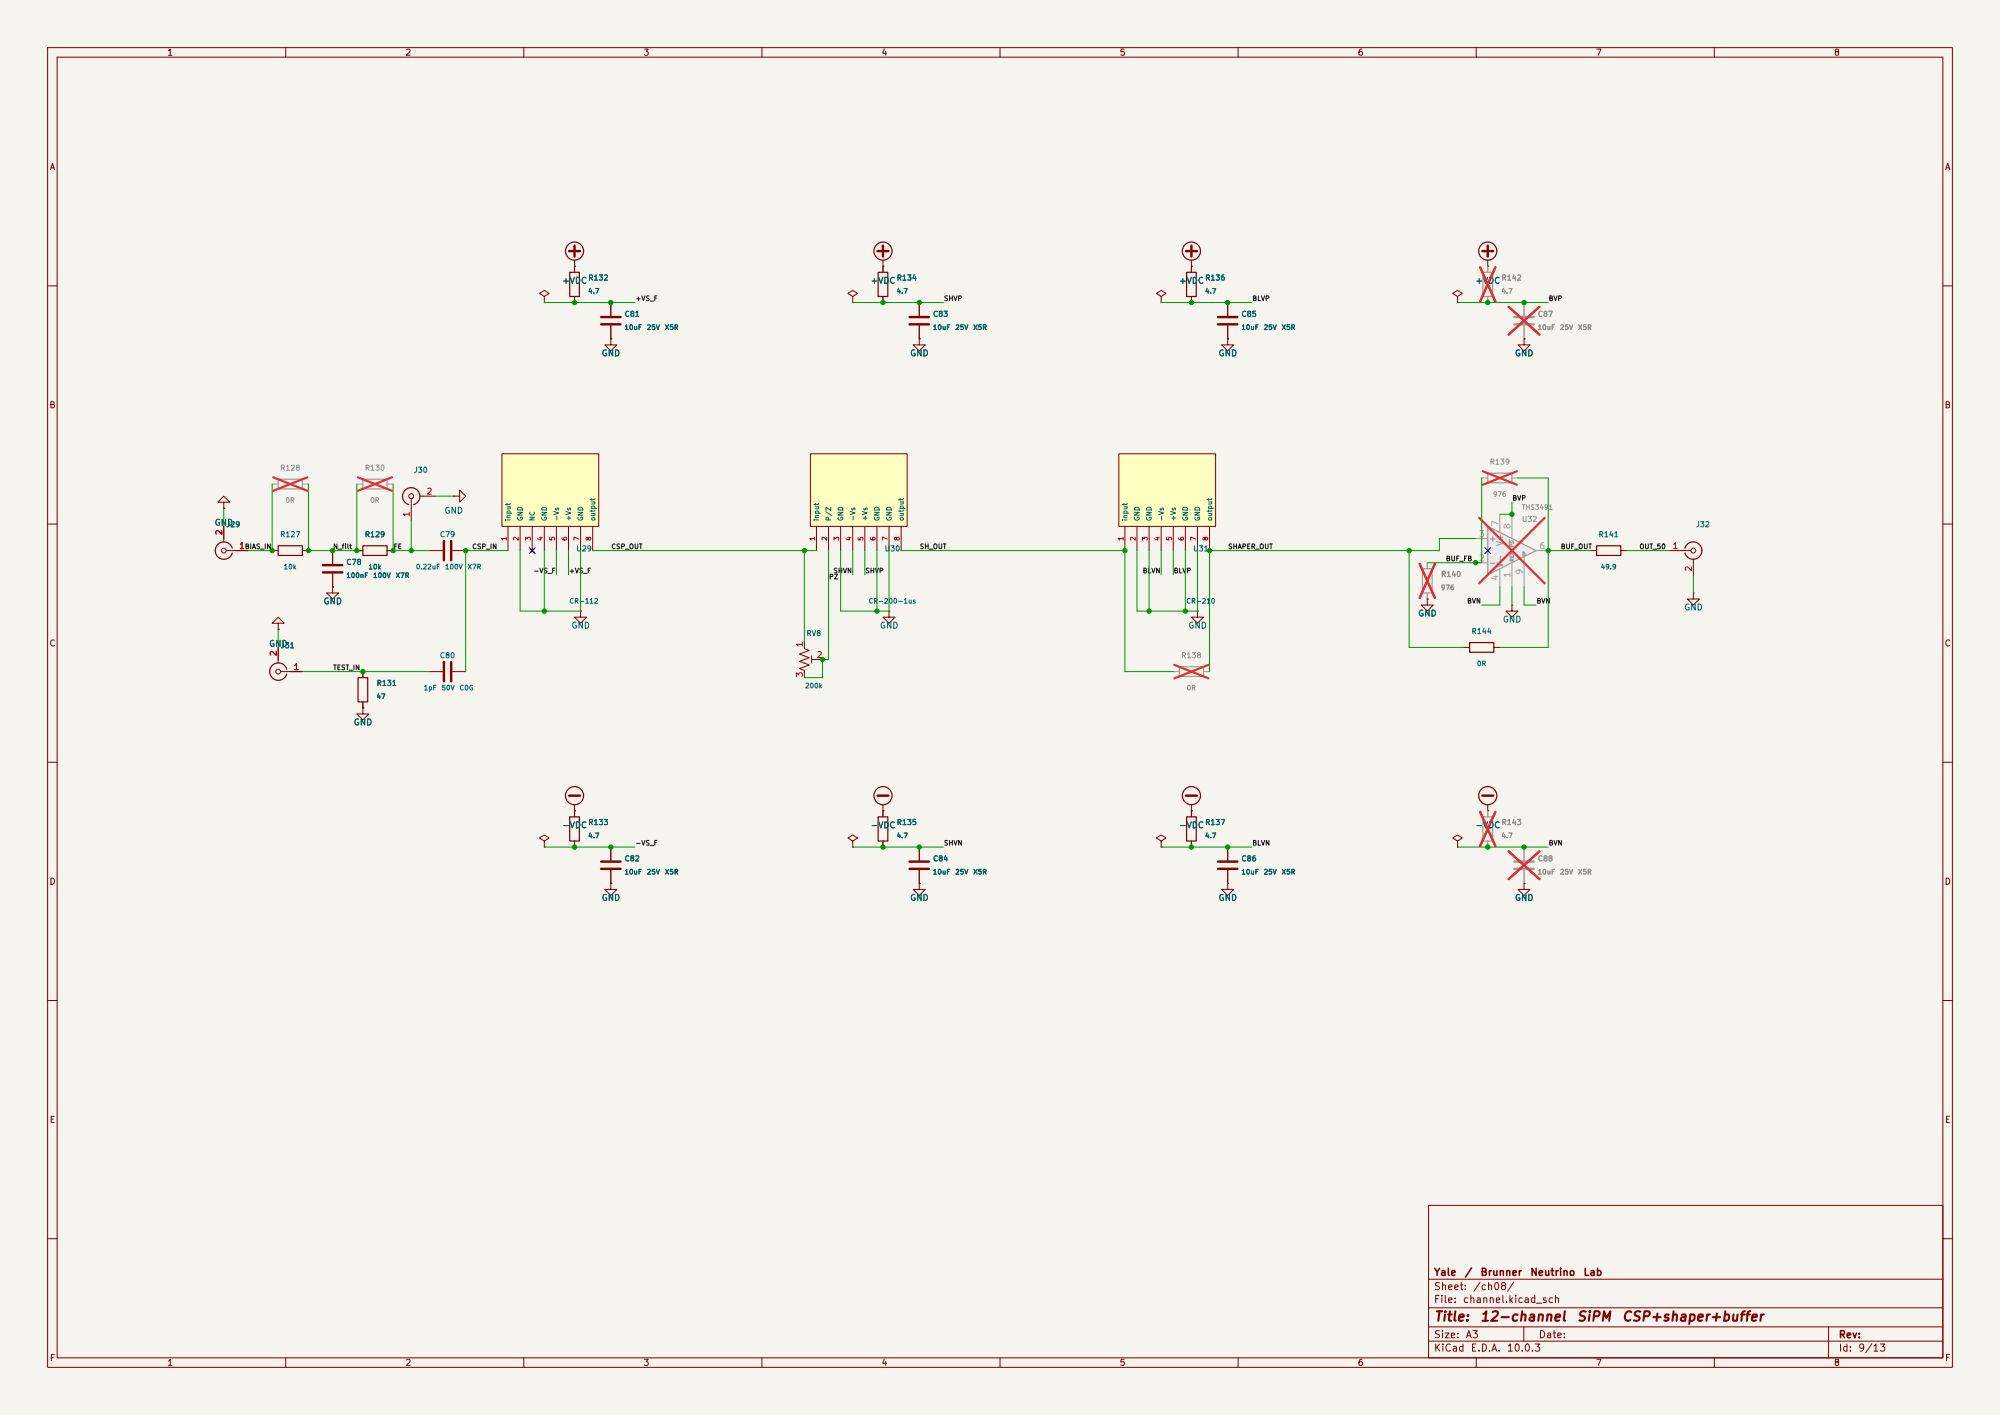
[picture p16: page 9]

Yale / Brunner Neutrino Lab
Sheet: /ch08/

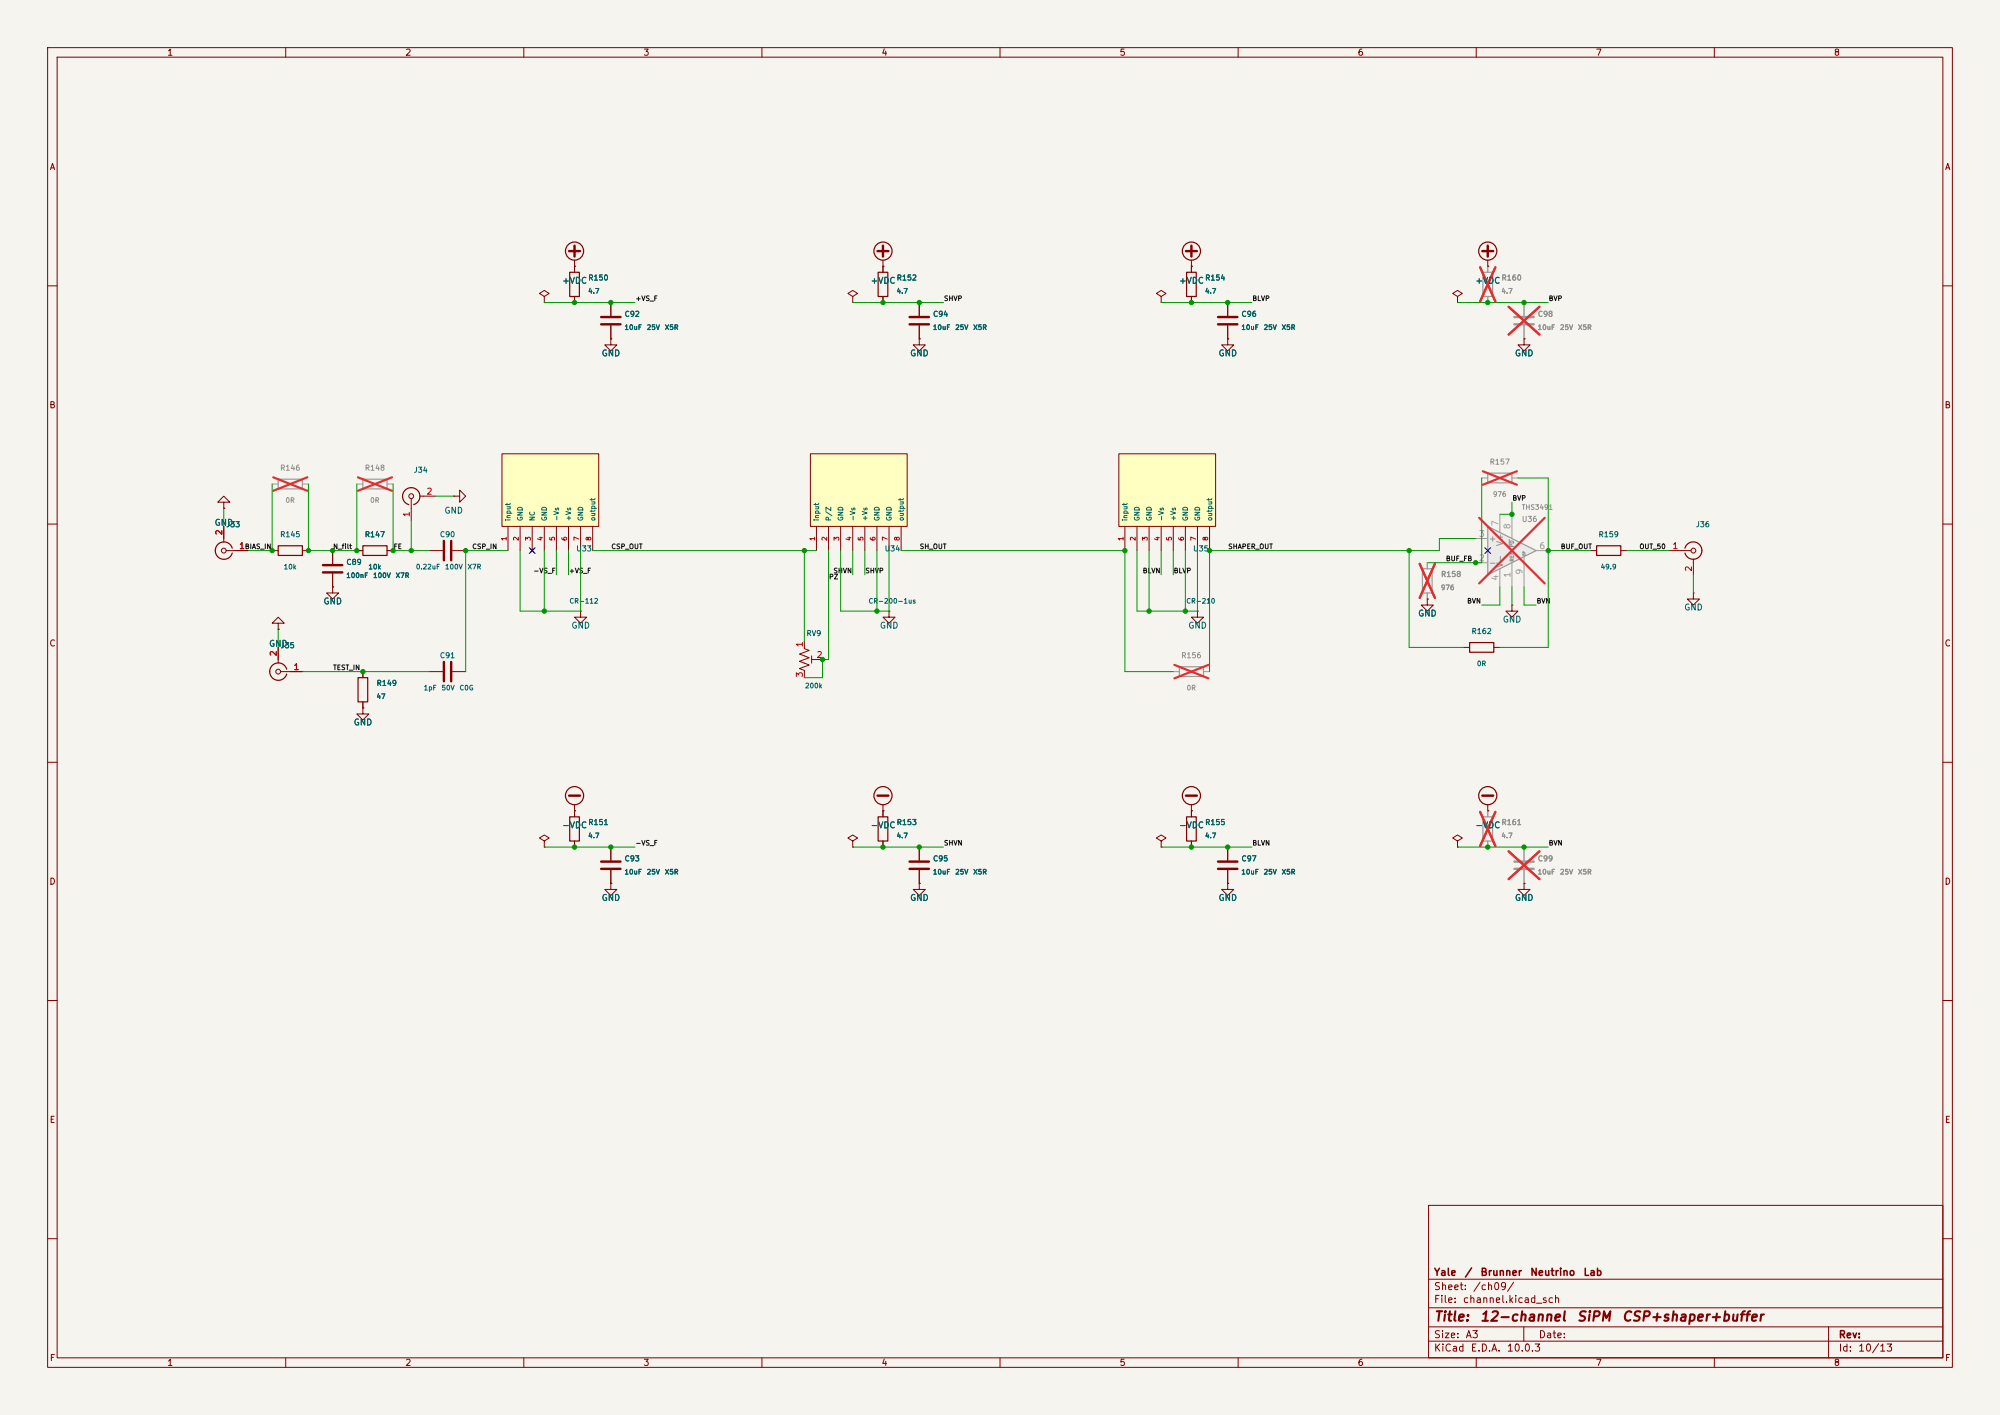
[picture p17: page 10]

Yale / Brunner Neutrino Lab
Sheet: /ch09/

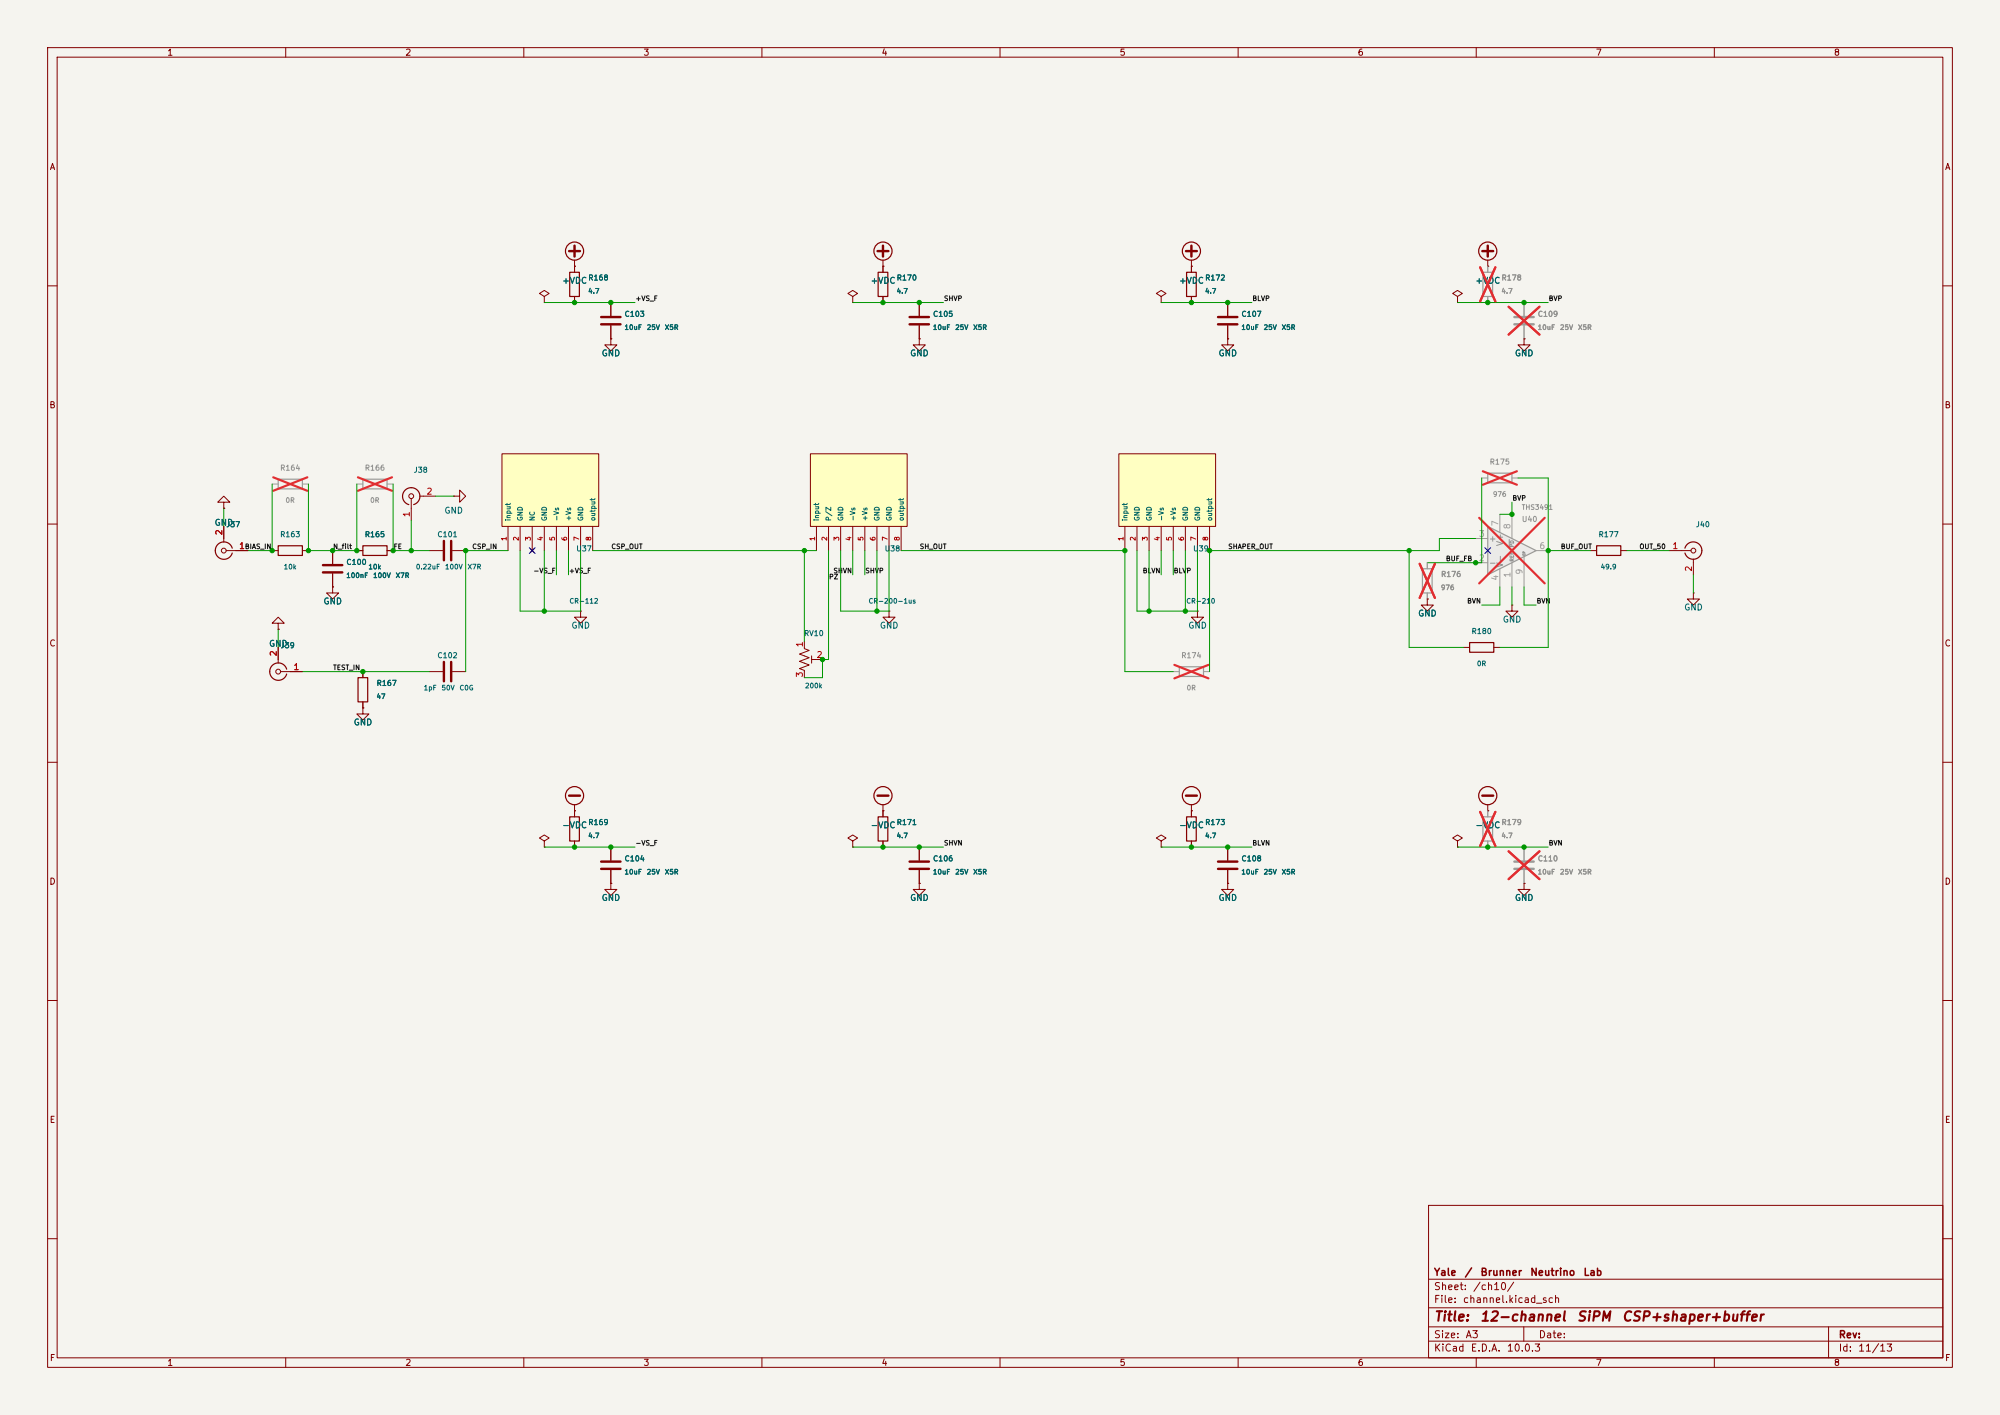
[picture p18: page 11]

Yale / Brunner Neutrino Lab
Sheet: /ch10/

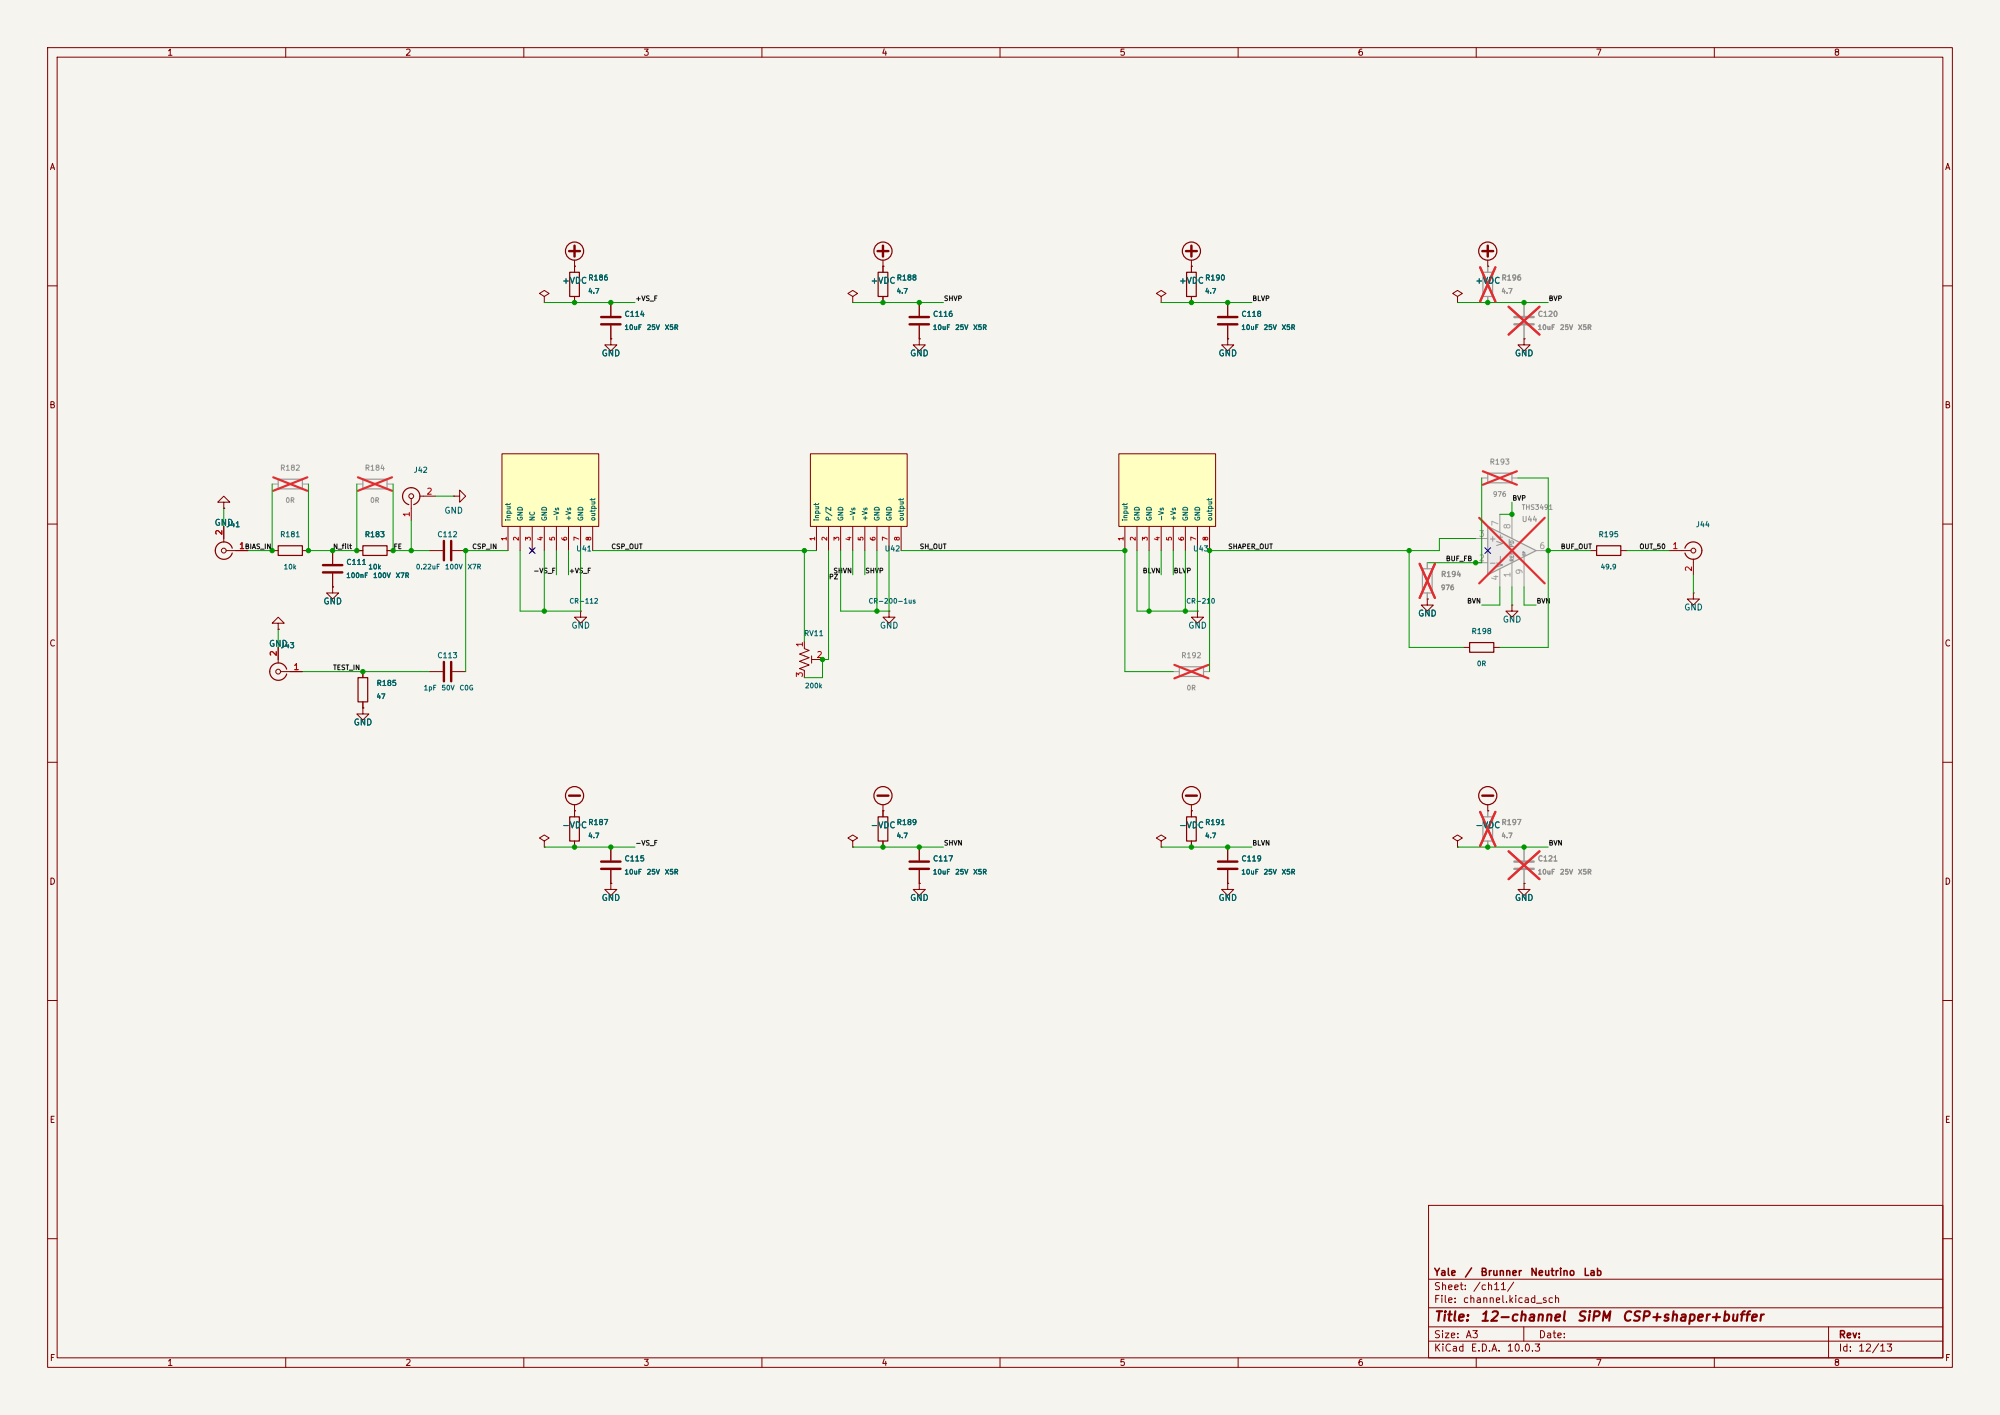
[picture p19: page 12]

Yale / Brunner Neutrino Lab
Sheet: /ch11/


Yale / Brunner Neutrino Lab
Sheet: /ch12/

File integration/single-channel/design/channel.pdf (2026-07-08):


Yale / Brunner Neutrino Lab
Sheet: /
File: channel.kicad_sch
Title: Single-channel SiPM CSP+shaper+buffer (channel)

Size: A3 | Rev: | F Date:
KiCad E.D.A. 10.0.3 | Id: 1/1

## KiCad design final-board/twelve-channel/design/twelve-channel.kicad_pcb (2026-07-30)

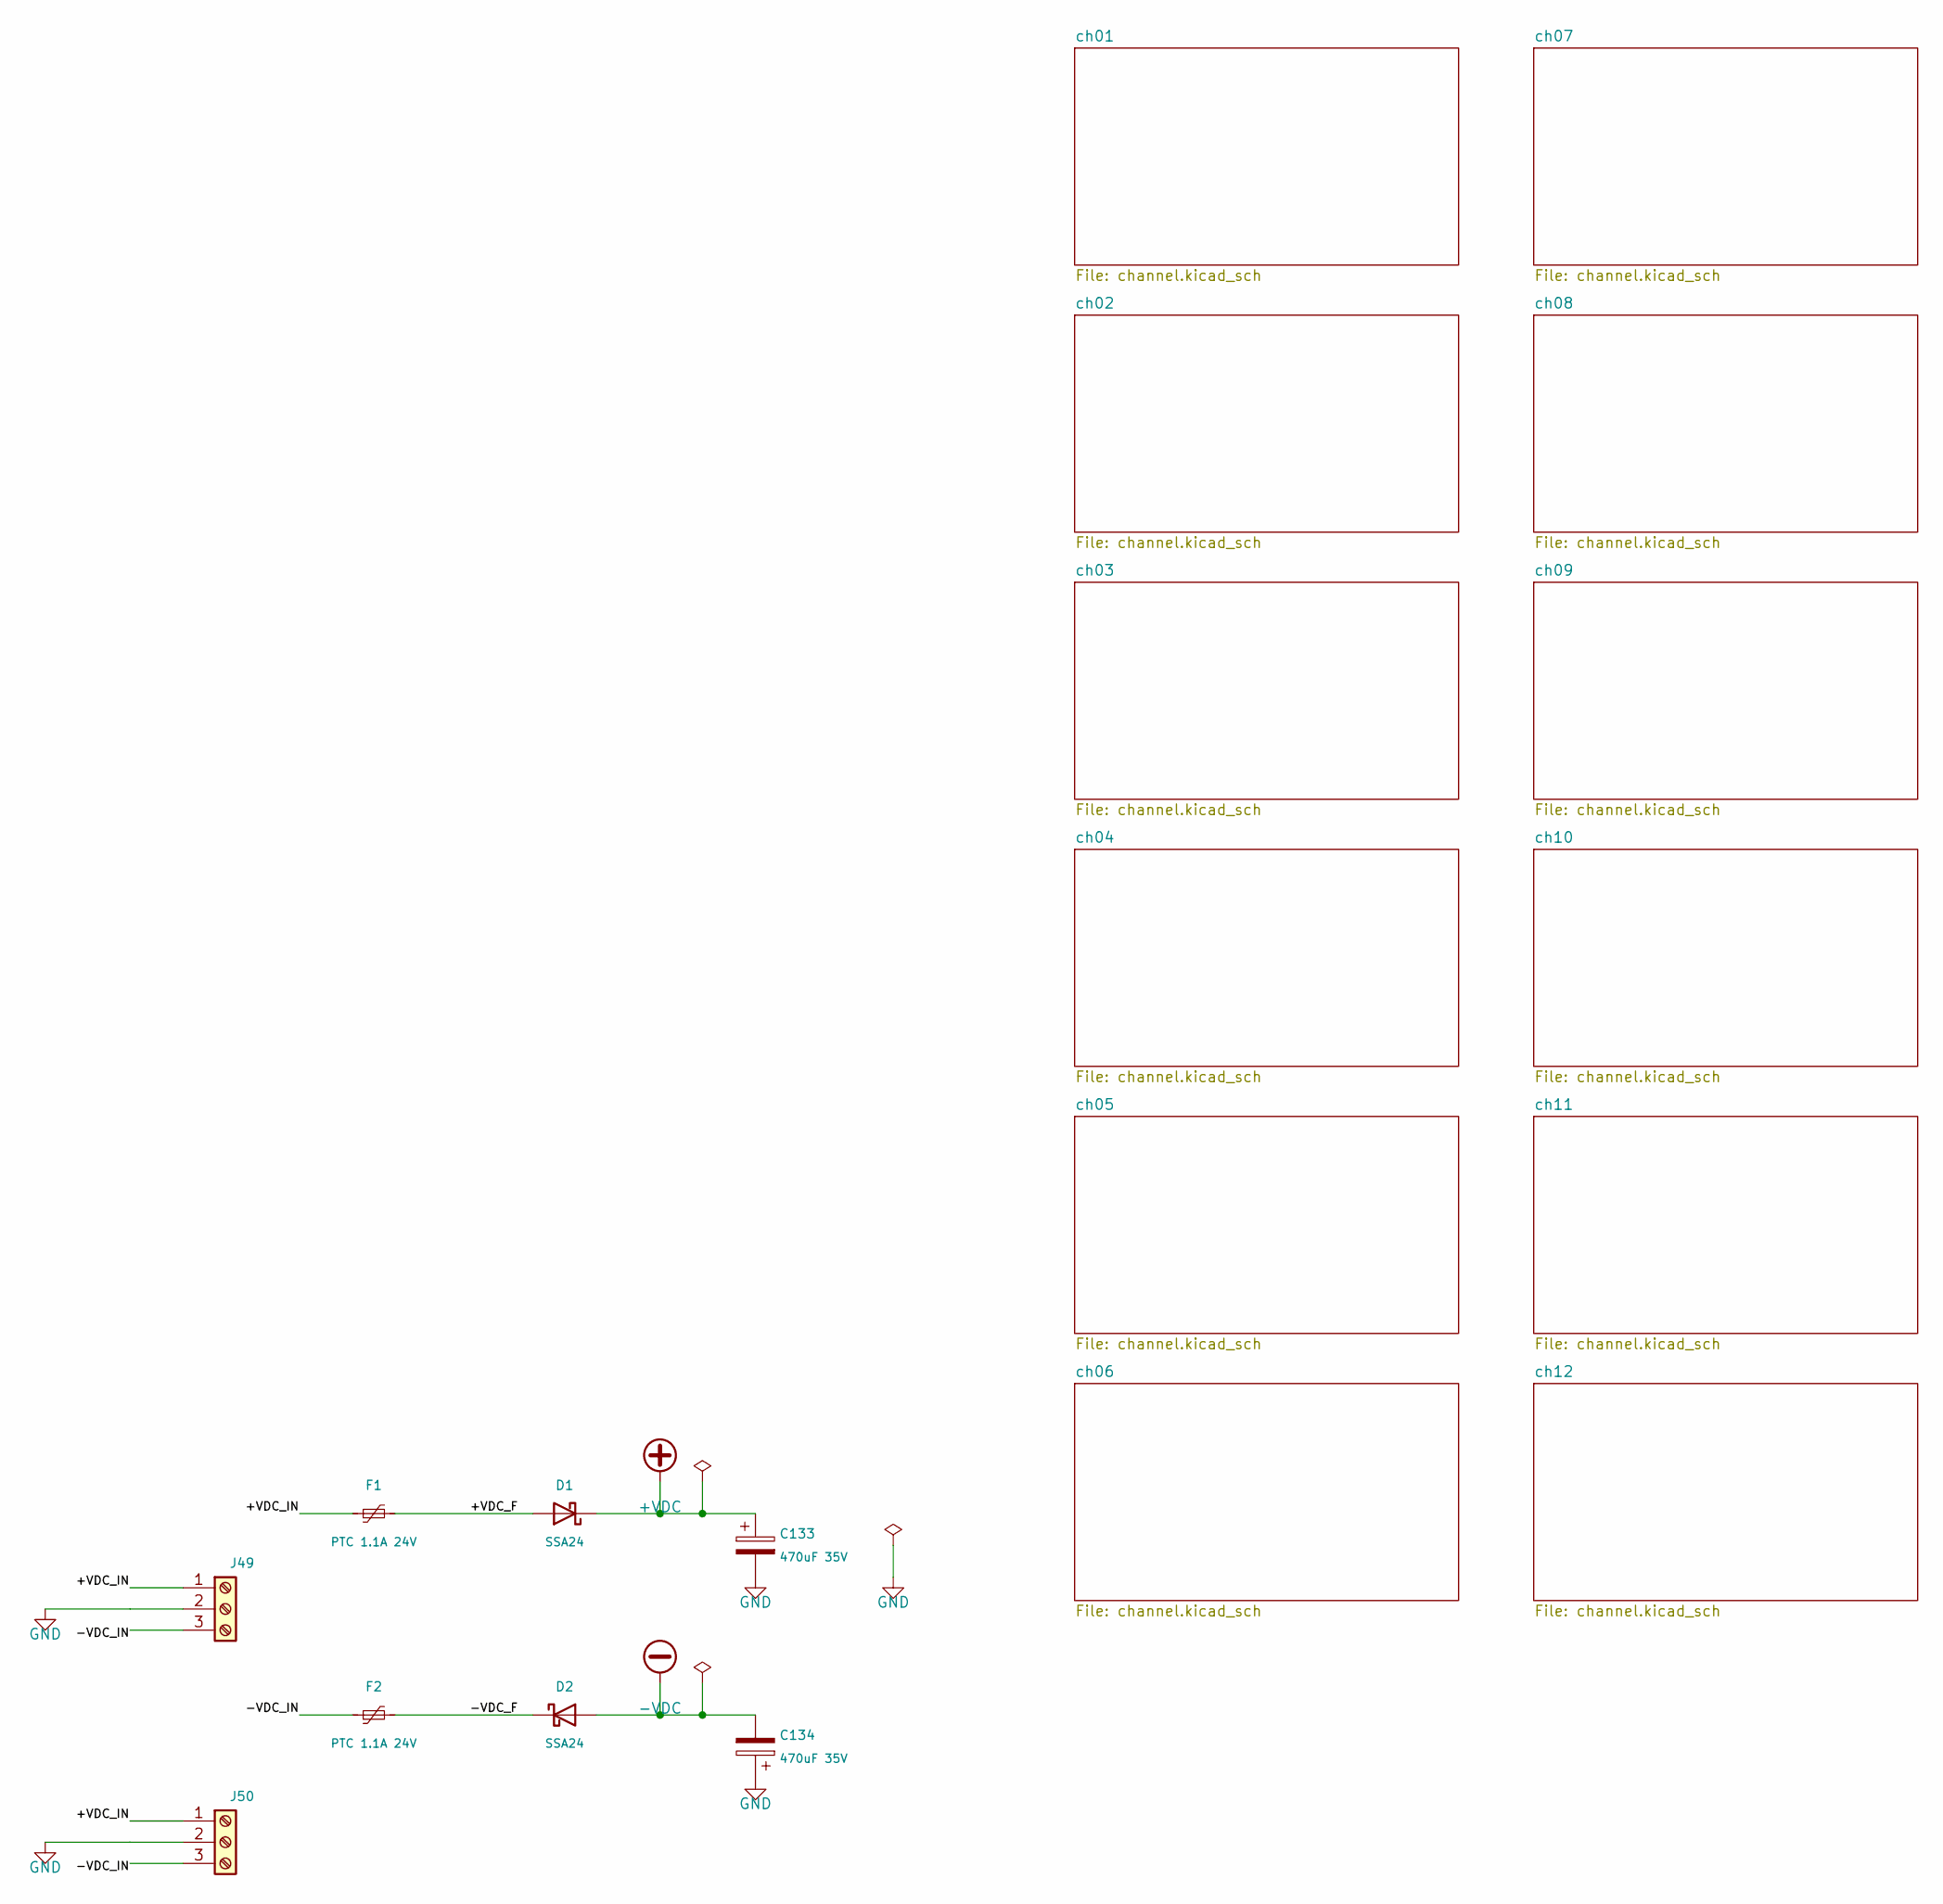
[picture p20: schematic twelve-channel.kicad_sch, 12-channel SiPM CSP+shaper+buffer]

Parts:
C133, C134: 470uF 35V; CP_Elec_10x10.5; MPN EEE-FN1V471UP
D1, D2: SSA24; D_SMA; MPN SSA24
F1, F2: PTC 1.1A 24V; Fuse_1812_4532Metric; MPN 1812L110/24DR
J49, J50: Screw terminal 3-pos 5.08mm; TerminalBlock_Phoenix_MKDS-1,5-3_1x03_P5.00mm_Horizontal; MPN 1715734

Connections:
+VDC: C133.1, D1.1 (K); also elsewhere on the board
-VDC: C134.2, D2.2 (A); also elsewhere on the board
/+VDC_F: D1.2 (A), F1.2
/+VDC_IN: F1.1, J49.1, J50.1
/-VDC_F: D2.1 (K), F2.2
/-VDC_IN: F2.1, J49.3, J50.3
GND: C133.2, C134.1, J49.2, J50.2; also elsewhere on the board

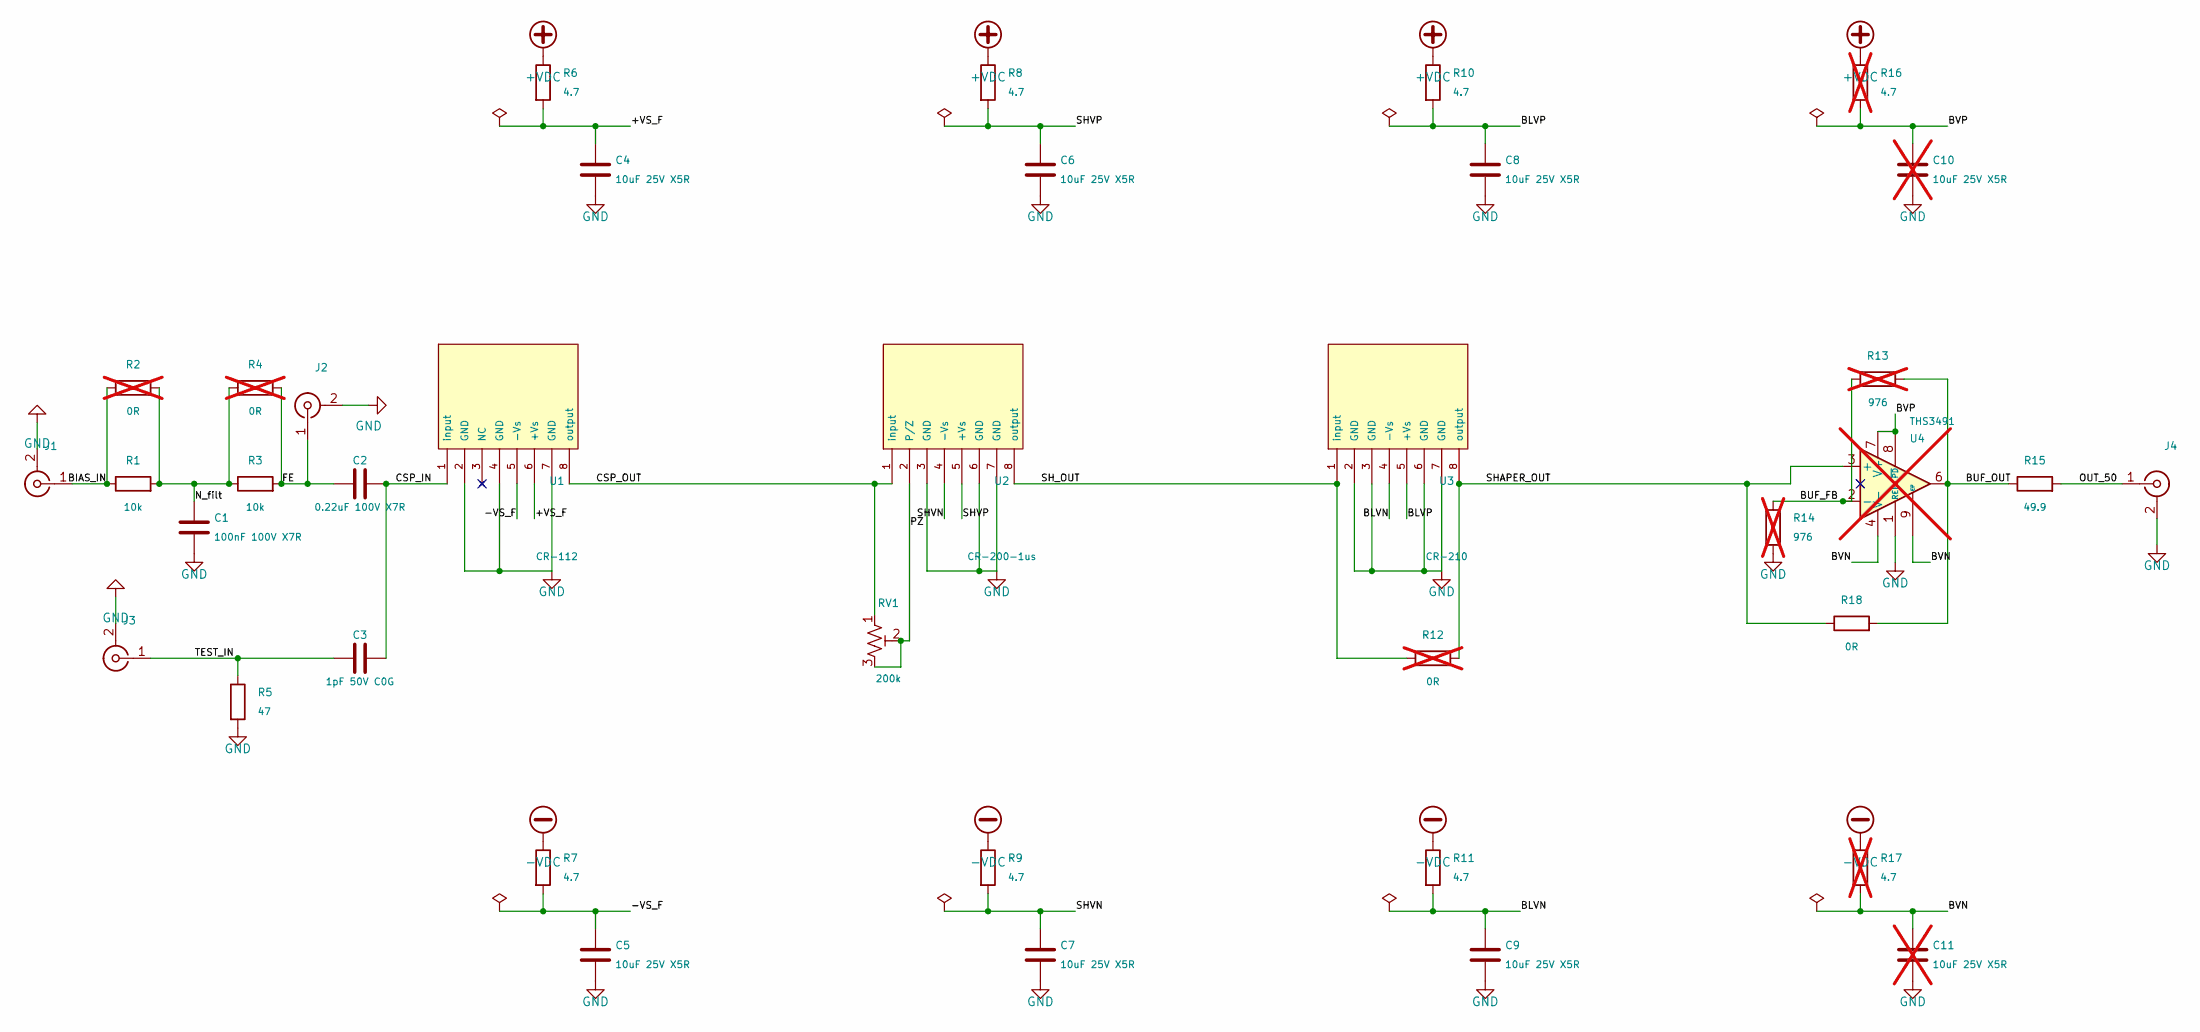
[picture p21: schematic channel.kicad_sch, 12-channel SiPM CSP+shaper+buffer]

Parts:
C1: 100nF 100V X7R; C_0805_2012Metric; MPN CL21B104KCFNNNE
C2: 0.22uF 100V X7R; C_0805_2012Metric; MPN C0805C224K1RACTU
C3: 1pF 50V C0G; C_0805_2012Metric; MPN CC0805CRNPO9BN1R0
C4, C5, C6, C7, C8, C9: 10uF 25V X5R; C_0805_2012Metric; MPN C0805C106K3PACTU
C10, C11: 10uF 25V X5R; C_0805_2012Metric; MPN C0805C106K3PACTU; not fitted
J1, J2, J3, J4: MCX edge jack 50R; MCX_CONMCX013-T; MPN CONMCX013
R1, R3: 10k; R_0805_2012Metric; MPN RC0805FR-0710KL
R2, R4, R12: 0R; R_0805_2012Metric; MPN RC0805JR-070RL; not fitted
R5: 47; R_0805_2012Metric; MPN RC0805JR-0747RL
R6, R7, R8, R9, R10, R11: 4.7; R_0805_2012Metric; MPN RC0805JR-074R7L
R13, R14: 976; R_0805_2012Metric; MPN RC0805FR-07976RL; not fitted
R15: 49.9; R_0805_2012Metric; MPN RC0805FR-0749R9L
R16, R17: 4.7; R_0805_2012Metric; MPN RC0805JR-074R7L; not fitted
R18: 0R; R_0805_2012Metric; MPN RC0805JR-070RL
RV1: 200k; Potentiometer_Bourns_3296W_Vertical; MPN 3296W-1-204LF
U1: CR-112; PinSocket_1x08_P2.54mm_Vertical; MPN CR-112-R2.1
U2: CR-200-1us; PinSocket_1x08_P2.54mm_Vertical; MPN CR-200-1us-R2.1
U3: CR-210; PinSocket_1x08_P2.54mm_Vertical; MPN CR-210-R0
U4: THS3491; SOIC-8-1EP_3.9x4.9mm_P1.27mm_EP2.29x3mm; MPN THS3491IDDAT; not fitted

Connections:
+VDC: R6.1, R8.1, R10.1, R16.1; also elsewhere on the board
-VDC: R7.1, R9.1, R11.1, R17.1; also elsewhere on the board
/ch01/+VS_F: C4.1, R6.2, U1.6 (+Vs)
/ch01/-VS_F: C5.1, R7.2, U1.5 (-Vs)
/ch01/BIAS_IN: J1.1 (In), R1.1, R2.1
/ch01/BLVN: C9.1, R11.2, U3.4 (-Vs)
/ch01/BLVP: C8.1, R10.2, U3.5 (+Vs)
/ch01/BUF_FB: R13.2, R14.1, U4.2 (-)
/ch01/BUF_OUT: R13.1, R15.1, R18.2, U4.6
/ch01/BVN: C11.1, R17.2, U4.4 (V-), U4.9 (EP)
/ch01/BVP: C10.1, R16.2, U4.7 (V+), U4.8 (~PD)
/ch01/CSP_IN: C2.2, C3.2, U1.1 (input)
/ch01/CSP_OUT: RV1.1, U1.8 (output), U2.1 (input)
/ch01/FE: C2.1, J2.1 (In), R3.2, R4.2
/ch01/N_filt: C1.1, R1.2, R2.2, R3.1, R4.1
/ch01/OUT_50: J4.1 (In), R15.2
/ch01/PZ: RV1.2, RV1.3, U2.2 (P/Z)
/ch01/SHAPER_OUT: R12.2, R18.1, U3.8 (output), U4.3 (+)
/ch01/SHVN: C7.1, R9.2, U2.4 (-Vs)
/ch01/SHVP: C6.1, R8.2, U2.5 (+Vs)
/ch01/SH_OUT: R12.1, U2.8 (output), U3.1 (input)
/ch01/TEST_IN: C3.1, J3.1 (In), R5.1
GND: C1.2, C4.2, C5.2, C6.2, C7.2, C8.2, C9.2, C10.2, C11.2, J1.2 (Ext), J2.2 (Ext), J3.2 (Ext), J4.2 (Ext), R5.2, R14.2, U1.2 (GND), U1.4 (GND), U1.7 (GND), U2.3 (GND), U2.6 (GND), U2.7 (GND), U3.2 (GND), U3.3 (GND), U3.6 (GND), U3.7 (GND), U4.1 (REF); also elsewhere on the board

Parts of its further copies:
C12, C23, C34, C45, C56, C67, C78, C89, C100, C111, C122: 100nF 100V X7R; C_0805_2012Metric; MPN CL21B104KCFNNNE
C13, C24, C35, C46, C57, C68, C79, C90, C101, C112, C123: 0.22uF 100V X7R; C_0805_2012Metric; MPN C0805C224K1RACTU
C14, C25, C36, C47, C58, C69, C80, C91, C102, C113, C124: 1pF 50V C0G; C_0805_2012Metric; MPN CC0805CRNPO9BN1R0
C15, C16, C17, C18, C19, C20, C26, C27, C28, C29, C30, C31, C37, C38, C39, C40, C41, C42, C48, C49, C50, C51, C52, C53, C59, C60, C61, C62, C63, C64, C70, C71, C72, C73, C74, C75, C81, C82, C83, C84, C85, C86, C92, C93, C94, C95, C96, C97, C103, C104, C105, C106, C107, C108, C114, C115, C116, C117, C118, C119, C125, C126, C127, C128, C129, C130: 10uF 25V X5R; C_0805_2012Metric; MPN C0805C106K3PACTU
C21, C22, C32, C33, C43, C44, C54, C55, C65, C66, C76, C77, C87, C88, C98, C99, C109, C110, C120, C121, C131, C132: 10uF 25V X5R; C_0805_2012Metric; MPN C0805C106K3PACTU; not fitted
J5, J6, J7, J8, J9, J10, J11, J12, J13, J14, J15, J16, J17, J18, J19, J20, J21, J22, J23, J24, J25, J26, J27, J28, J29, J30, J31, J32, J33, J34, J35, J36, J37, J38, J39, J40, J41, J42, J43, J44, J45, J46, J47, J48: MCX edge jack 50R; MCX_CONMCX013-T; MPN CONMCX013
R19, R21, R37, R39, R55, R57, R73, R75, R91, R93, R109, R111, R127, R129, R145, R147, R163, R165, R181, R183, R199, R201: 10k; R_0805_2012Metric; MPN RC0805FR-0710KL
R20, R22, R30, R38, R40, R48, R56, R58, R66, R74, R76, R84, R92, R94, R102, R110, R112, R120, R128, R130, R138, R146, R148, R156, R164, R166, R174, R182, R184, R192, R200, R202, R210: 0R; R_0805_2012Metric; MPN RC0805JR-070RL; not fitted
R23, R41, R59, R77, R95, R113, R131, R149, R167, R185, R203: 47; R_0805_2012Metric; MPN RC0805JR-0747RL
R24, R25, R26, R27, R28, R29, R42, R43, R44, R45, R46, R47, R60, R61, R62, R63, R64, R65, R78, R79, R80, R81, R82, R83, R96, R97, R98, R99, R100, R101, R114, R115, R116, R117, R118, R119, R132, R133, R134, R135, R136, R137, R150, R151, R152, R153, R154, R155, R168, R169, R170, R171, R172, R173, R186, R187, R188, R189, R190, R191, R204, R205, R206, R207, R208, R209: 4.7; R_0805_2012Metric; MPN RC0805JR-074R7L
R31, R32, R49, R50, R67, R68, R85, R86, R103, R104, R121, R122, R139, R140, R157, R158, R175, R176, R193, R194, R211, R212: 976; R_0805_2012Metric; MPN RC0805FR-07976RL; not fitted
R33, R51, R69, R87, R105, R123, R141, R159, R177, R195, R213: 49.9; R_0805_2012Metric; MPN RC0805FR-0749R9L
R34, R35, R52, R53, R70, R71, R88, R89, R106, R107, R124, R125, R142, R143, R160, R161, R178, R179, R196, R197, R214, R215: 4.7; R_0805_2012Metric; MPN RC0805JR-074R7L; not fitted
R36, R54, R72, R90, R108, R126, R144, R162, R180, R198, R216: 0R; R_0805_2012Metric; MPN RC0805JR-070RL
RV2, RV3, RV4, RV5, RV6, RV7, RV8, RV9, RV10, RV11, RV12: 200k; Potentiometer_Bourns_3296W_Vertical; MPN 3296W-1-204LF
U5, U9, U13, U17, U21, U25, U29, U33, U37, U41, U45: CR-112; PinSocket_1x08_P2.54mm_Vertical; MPN CR-112-R2.1
U6, U10, U14, U18, U22, U26, U30, U34, U38, U42, U46: CR-200-1us; PinSocket_1x08_P2.54mm_Vertical; MPN CR-200-1us-R2.1
U7, U11, U15, U19, U23, U27, U31, U35, U39, U43, U47: CR-210; PinSocket_1x08_P2.54mm_Vertical; MPN CR-210-R0
U8, U12, U16, U20, U24, U28, U32, U36, U40, U44, U48: THS3491; SOIC-8-1EP_3.9x4.9mm_P1.27mm_EP2.29x3mm; MPN THS3491IDDAT; not fitted

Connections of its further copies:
+VDC: R24.1, R26.1, R28.1, R34.1, R42.1, R44.1, R46.1, R52.1, R60.1, R62.1, R64.1, R70.1, R78.1, R80.1, R82.1, R88.1, R96.1, R98.1, R100.1, R106.1, R114.1, R116.1, R118.1, R124.1, R132.1, R134.1, R136.1, R142.1, R150.1, R152.1, R154.1, R160.1, R168.1, R170.1, R172.1, R178.1, R186.1, R188.1, R190.1, R196.1, R204.1, R206.1, R208.1, R214.1; also elsewhere on the board
-VDC: R25.1, R27.1, R29.1, R35.1, R43.1, R45.1, R47.1, R53.1, R61.1, R63.1, R65.1, R71.1, R79.1, R81.1, R83.1, R89.1, R97.1, R99.1, R101.1, R107.1, R115.1, R117.1, R119.1, R125.1, R133.1, R135.1, R137.1, R143.1, R151.1, R153.1, R155.1, R161.1, R169.1, R171.1, R173.1, R179.1, R187.1, R189.1, R191.1, R197.1, R205.1, R207.1, R209.1, R215.1; also elsewhere on the board
/ch02/+VS_F: C15.1, R24.2, U5.6 (+Vs)
/ch02/-VS_F: C16.1, R25.2, U5.5 (-Vs)
/ch02/BIAS_IN: J5.1 (In), R19.1, R20.1
/ch02/BLVN: C20.1, R29.2, U7.4 (-Vs)
/ch02/BLVP: C19.1, R28.2, U7.5 (+Vs)
/ch02/BUF_FB: R31.2, R32.1, U8.2 (-)
/ch02/BUF_OUT: R31.1, R33.1, R36.2, U8.6
/ch02/BVN: C22.1, R35.2, U8.4 (V-), U8.9 (EP)
/ch02/BVP: C21.1, R34.2, U8.7 (V+), U8.8 (~PD)
/ch02/CSP_IN: C13.2, C14.2, U5.1 (input)
/ch02/CSP_OUT: RV2.1, U5.8 (output), U6.1 (input)
/ch02/FE: C13.1, J6.1 (In), R21.2, R22.2
/ch02/N_filt: C12.1, R19.2, R20.2, R21.1, R22.1
/ch02/OUT_50: J8.1 (In), R33.2
/ch02/PZ: RV2.2, RV2.3, U6.2 (P/Z)
/ch02/SHAPER_OUT: R30.2, R36.1, U7.8 (output), U8.3 (+)
/ch02/SHVN: C18.1, R27.2, U6.4 (-Vs)
/ch02/SHVP: C17.1, R26.2, U6.5 (+Vs)
/ch02/SH_OUT: R30.1, U6.8 (output), U7.1 (input)
/ch02/TEST_IN: C14.1, J7.1 (In), R23.1
/ch03/+VS_F: C26.1, R42.2, U9.6 (+Vs)
/ch03/-VS_F: C27.1, R43.2, U9.5 (-Vs)
/ch03/BIAS_IN: J9.1 (In), R37.1, R38.1
/ch03/BLVN: C31.1, R47.2, U11.4 (-Vs)
/ch03/BLVP: C30.1, R46.2, U11.5 (+Vs)
/ch03/BUF_FB: R49.2, R50.1, U12.2 (-)
/ch03/BUF_OUT: R49.1, R51.1, R54.2, U12.6
/ch03/BVN: C33.1, R53.2, U12.4 (V-), U12.9 (EP)
/ch03/BVP: C32.1, R52.2, U12.7 (V+), U12.8 (~PD)
/ch03/CSP_IN: C24.2, C25.2, U9.1 (input)
/ch03/CSP_OUT: RV3.1, U9.8 (output), U10.1 (input)
/ch03/FE: C24.1, J10.1 (In), R39.2, R40.2
/ch03/N_filt: C23.1, R37.2, R38.2, R39.1, R40.1
/ch03/OUT_50: J12.1 (In), R51.2
/ch03/PZ: RV3.2, RV3.3, U10.2 (P/Z)
/ch03/SHAPER_OUT: R48.2, R54.1, U11.8 (output), U12.3 (+)
/ch03/SHVN: C29.1, R45.2, U10.4 (-Vs)
/ch03/SHVP: C28.1, R44.2, U10.5 (+Vs)
/ch03/SH_OUT: R48.1, U10.8 (output), U11.1 (input)
/ch03/TEST_IN: C25.1, J11.1 (In), R41.1
/ch04/+VS_F: C37.1, R60.2, U13.6 (+Vs)
/ch04/-VS_F: C38.1, R61.2, U13.5 (-Vs)
/ch04/BIAS_IN: J13.1 (In), R55.1, R56.1
/ch04/BLVN: C42.1, R65.2, U15.4 (-Vs)
/ch04/BLVP: C41.1, R64.2, U15.5 (+Vs)
/ch04/BUF_FB: R67.2, R68.1, U16.2 (-)
/ch04/BUF_OUT: R67.1, R69.1, R72.2, U16.6
/ch04/BVN: C44.1, R71.2, U16.4 (V-), U16.9 (EP)
/ch04/BVP: C43.1, R70.2, U16.7 (V+), U16.8 (~PD)
/ch04/CSP_IN: C35.2, C36.2, U13.1 (input)
/ch04/CSP_OUT: RV4.1, U13.8 (output), U14.1 (input)
/ch04/FE: C35.1, J14.1 (In), R57.2, R58.2
/ch04/N_filt: C34.1, R55.2, R56.2, R57.1, R58.1
/ch04/OUT_50: J16.1 (In), R69.2
/ch04/PZ: RV4.2, RV4.3, U14.2 (P/Z)
/ch04/SHAPER_OUT: R66.2, R72.1, U15.8 (output), U16.3 (+)
/ch04/SHVN: C40.1, R63.2, U14.4 (-Vs)
/ch04/SHVP: C39.1, R62.2, U14.5 (+Vs)
/ch04/SH_OUT: R66.1, U14.8 (output), U15.1 (input)
/ch04/TEST_IN: C36.1, J15.1 (In), R59.1
/ch05/+VS_F: C48.1, R78.2, U17.6 (+Vs)
/ch05/-VS_F: C49.1, R79.2, U17.5 (-Vs)
/ch05/BIAS_IN: J17.1 (In), R73.1, R74.1
/ch05/BLVN: C53.1, R83.2, U19.4 (-Vs)
/ch05/BLVP: C52.1, R82.2, U19.5 (+Vs)
/ch05/BUF_FB: R85.2, R86.1, U20.2 (-)
/ch05/BUF_OUT: R85.1, R87.1, R90.2, U20.6
/ch05/BVN: C55.1, R89.2, U20.4 (V-), U20.9 (EP)
/ch05/BVP: C54.1, R88.2, U20.7 (V+), U20.8 (~PD)
/ch05/CSP_IN: C46.2, C47.2, U17.1 (input)
/ch05/CSP_OUT: RV5.1, U17.8 (output), U18.1 (input)
/ch05/FE: C46.1, J18.1 (In), R75.2, R76.2
/ch05/N_filt: C45.1, R73.2, R74.2, R75.1, R76.1
/ch05/OUT_50: J20.1 (In), R87.2
/ch05/PZ: RV5.2, RV5.3, U18.2 (P/Z)
/ch05/SHAPER_OUT: R84.2, R90.1, U19.8 (output), U20.3 (+)
/ch05/SHVN: C51.1, R81.2, U18.4 (-Vs)
/ch05/SHVP: C50.1, R80.2, U18.5 (+Vs)
/ch05/SH_OUT: R84.1, U18.8 (output), U19.1 (input)
/ch05/TEST_IN: C47.1, J19.1 (In), R77.1
/ch06/+VS_F: C59.1, R96.2, U21.6 (+Vs)
/ch06/-VS_F: C60.1, R97.2, U21.5 (-Vs)
/ch06/BIAS_IN: J21.1 (In), R91.1, R92.1
/ch06/BLVN: C64.1, R101.2, U23.4 (-Vs)
/ch06/BLVP: C63.1, R100.2, U23.5 (+Vs)
/ch06/BUF_FB: R103.2, R104.1, U24.2 (-)
/ch06/BUF_OUT: R103.1, R105.1, R108.2, U24.6
/ch06/BVN: C66.1, R107.2, U24.4 (V-), U24.9 (EP)
/ch06/BVP: C65.1, R106.2, U24.7 (V+), U24.8 (~PD)
/ch06/CSP_IN: C57.2, C58.2, U21.1 (input)
/ch06/CSP_OUT: RV6.1, U21.8 (output), U22.1 (input)
/ch06/FE: C57.1, J22.1 (In), R93.2, R94.2
/ch06/N_filt: C56.1, R91.2, R92.2, R93.1, R94.1
/ch06/OUT_50: J24.1 (In), R105.2
/ch06/PZ: RV6.2, RV6.3, U22.2 (P/Z)
/ch06/SHAPER_OUT: R102.2, R108.1, U23.8 (output), U24.3 (+)
/ch06/SHVN: C62.1, R99.2, U22.4 (-Vs)
/ch06/SHVP: C61.1, R98.2, U22.5 (+Vs)
/ch06/SH_OUT: R102.1, U22.8 (output), U23.1 (input)
/ch06/TEST_IN: C58.1, J23.1 (In), R95.1
/ch07/+VS_F: C70.1, R114.2, U25.6 (+Vs)
/ch07/-VS_F: C71.1, R115.2, U25.5 (-Vs)
/ch07/BIAS_IN: J25.1 (In), R109.1, R110.1
/ch07/BLVN: C75.1, R119.2, U27.4 (-Vs)
/ch07/BLVP: C74.1, R118.2, U27.5 (+Vs)
/ch07/BUF_FB: R121.2, R122.1, U28.2 (-)
/ch07/BUF_OUT: R121.1, R123.1, R126.2, U28.6
/ch07/BVN: C77.1, R125.2, U28.4 (V-), U28.9 (EP)
/ch07/BVP: C76.1, R124.2, U28.7 (V+), U28.8 (~PD)
/ch07/CSP_IN: C68.2, C69.2, U25.1 (input)
/ch07/CSP_OUT: RV7.1, U25.8 (output), U26.1 (input)
/ch07/FE: C68.1, J26.1 (In), R111.2, R112.2
/ch07/N_filt: C67.1, R109.2, R110.2, R111.1, R112.1
/ch07/OUT_50: J28.1 (In), R123.2
/ch07/PZ: RV7.2, RV7.3, U26.2 (P/Z)
/ch07/SHAPER_OUT: R120.2, R126.1, U27.8 (output), U28.3 (+)
/ch07/SHVN: C73.1, R117.2, U26.4 (-Vs)
/ch07/SHVP: C72.1, R116.2, U26.5 (+Vs)
/ch07/SH_OUT: R120.1, U26.8 (output), U27.1 (input)
/ch07/TEST_IN: C69.1, J27.1 (In), R113.1
/ch08/+VS_F: C81.1, R132.2, U29.6 (+Vs)
/ch08/-VS_F: C82.1, R133.2, U29.5 (-Vs)
/ch08/BIAS_IN: J29.1 (In), R127.1, R128.1
/ch08/BLVN: C86.1, R137.2, U31.4 (-Vs)
/ch08/BLVP: C85.1, R136.2, U31.5 (+Vs)
/ch08/BUF_FB: R139.2, R140.1, U32.2 (-)
/ch08/BUF_OUT: R139.1, R141.1, R144.2, U32.6
/ch08/BVN: C88.1, R143.2, U32.4 (V-), U32.9 (EP)
/ch08/BVP: C87.1, R142.2, U32.7 (V+), U32.8 (~PD)
/ch08/CSP_IN: C79.2, C80.2, U29.1 (input)
/ch08/CSP_OUT: RV8.1, U29.8 (output), U30.1 (input)
/ch08/FE: C79.1, J30.1 (In), R129.2, R130.2
/ch08/N_filt: C78.1, R127.2, R128.2, R129.1, R130.1
/ch08/OUT_50: J32.1 (In), R141.2
/ch08/PZ: RV8.2, RV8.3, U30.2 (P/Z)
/ch08/SHAPER_OUT: R138.2, R144.1, U31.8 (output), U32.3 (+)
/ch08/SHVN: C84.1, R135.2, U30.4 (-Vs)
/ch08/SHVP: C83.1, R134.2, U30.5 (+Vs)
/ch08/SH_OUT: R138.1, U30.8 (output), U31.1 (input)
/ch08/TEST_IN: C80.1, J31.1 (In), R131.1
/ch09/+VS_F: C92.1, R150.2, U33.6 (+Vs)
/ch09/-VS_F: C93.1, R151.2, U33.5 (-Vs)
/ch09/BIAS_IN: J33.1 (In), R145.1, R146.1
/ch09/BLVN: C97.1, R155.2, U35.4 (-Vs)
/ch09/BLVP: C96.1, R154.2, U35.5 (+Vs)
/ch09/BUF_FB: R157.2, R158.1, U36.2 (-)
/ch09/BUF_OUT: R157.1, R159.1, R162.2, U36.6
/ch09/BVN: C99.1, R161.2, U36.4 (V-), U36.9 (EP)
/ch09/BVP: C98.1, R160.2, U36.7 (V+), U36.8 (~PD)
/ch09/CSP_IN: C90.2, C91.2, U33.1 (input)
/ch09/CSP_OUT: RV9.1, U33.8 (output), U34.1 (input)
/ch09/FE: C90.1, J34.1 (In), R147.2, R148.2
/ch09/N_filt: C89.1, R145.2, R146.2, R147.1, R148.1
/ch09/OUT_50: J36.1 (In), R159.2
/ch09/PZ: RV9.2, RV9.3, U34.2 (P/Z)
/ch09/SHAPER_OUT: R156.2, R162.1, U35.8 (output), U36.3 (+)
/ch09/SHVN: C95.1, R153.2, U34.4 (-Vs)
/ch09/SHVP: C94.1, R152.2, U34.5 (+Vs)
/ch09/SH_OUT: R156.1, U34.8 (output), U35.1 (input)
/ch09/TEST_IN: C91.1, J35.1 (In), R149.1
/ch10/+VS_F: C103.1, R168.2, U37.6 (+Vs)
/ch10/-VS_F: C104.1, R169.2, U37.5 (-Vs)
/ch10/BIAS_IN: J37.1 (In), R163.1, R164.1
/ch10/BLVN: C108.1, R173.2, U39.4 (-Vs)
/ch10/BLVP: C107.1, R172.2, U39.5 (+Vs)
/ch10/BUF_FB: R175.2, R176.1, U40.2 (-)
/ch10/BUF_OUT: R175.1, R177.1, R180.2, U40.6
/ch10/BVN: C110.1, R179.2, U40.4 (V-), U40.9 (EP)
/ch10/BVP: C109.1, R178.2, U40.7 (V+), U40.8 (~PD)
/ch10/CSP_IN: C101.2, C102.2, U37.1 (input)
/ch10/CSP_OUT: RV10.1, U37.8 (output), U38.1 (input)
/ch10/FE: C101.1, J38.1 (In), R165.2, R166.2
/ch10/N_filt: C100.1, R163.2, R164.2, R165.1, R166.1
/ch10/OUT_50: J40.1 (In), R177.2
/ch10/PZ: RV10.2, RV10.3, U38.2 (P/Z)
/ch10/SHAPER_OUT: R174.2, R180.1, U39.8 (output), U40.3 (+)
/ch10/SHVN: C106.1, R171.2, U38.4 (-Vs)
/ch10/SHVP: C105.1, R170.2, U38.5 (+Vs)
/ch10/SH_OUT: R174.1, U38.8 (output), U39.1 (input)
/ch10/TEST_IN: C102.1, J39.1 (In), R167.1
/ch11/+VS_F: C114.1, R186.2, U41.6 (+Vs)
/ch11/-VS_F: C115.1, R187.2, U41.5 (-Vs)
/ch11/BIAS_IN: J41.1 (In), R181.1, R182.1
/ch11/BLVN: C119.1, R191.2, U43.4 (-Vs)
/ch11/BLVP: C118.1, R190.2, U43.5 (+Vs)
/ch11/BUF_FB: R193.2, R194.1, U44.2 (-)
/ch11/BUF_OUT: R193.1, R195.1, R198.2, U44.6
/ch11/BVN: C121.1, R197.2, U44.4 (V-), U44.9 (EP)
/ch11/BVP: C120.1, R196.2, U44.7 (V+), U44.8 (~PD)
/ch11/CSP_IN: C112.2, C113.2, U41.1 (input)
/ch11/CSP_OUT: RV11.1, U41.8 (output), U42.1 (input)
/ch11/FE: C112.1, J42.1 (In), R183.2, R184.2
/ch11/N_filt: C111.1, R181.2, R182.2, R183.1, R184.1
/ch11/OUT_50: J44.1 (In), R195.2
/ch11/PZ: RV11.2, RV11.3, U42.2 (P/Z)
/ch11/SHAPER_OUT: R192.2, R198.1, U43.8 (output), U44.3 (+)
/ch11/SHVN: C117.1, R189.2, U42.4 (-Vs)
/ch11/SHVP: C116.1, R188.2, U42.5 (+Vs)
/ch11/SH_OUT: R192.1, U42.8 (output), U43.1 (input)
/ch11/TEST_IN: C113.1, J43.1 (In), R185.1
/ch12/+VS_F: C125.1, R204.2, U45.6 (+Vs)
/ch12/-VS_F: C126.1, R205.2, U45.5 (-Vs)
/ch12/BIAS_IN: J45.1 (In), R199.1, R200.1
/ch12/BLVN: C130.1, R209.2, U47.4 (-Vs)
/ch12/BLVP: C129.1, R208.2, U47.5 (+Vs)
/ch12/BUF_FB: R211.2, R212.1, U48.2 (-)
/ch12/BUF_OUT: R211.1, R213.1, R216.2, U48.6
/ch12/BVN: C132.1, R215.2, U48.4 (V-), U48.9 (EP)
/ch12/BVP: C131.1, R214.2, U48.7 (V+), U48.8 (~PD)
/ch12/CSP_IN: C123.2, C124.2, U45.1 (input)
/ch12/CSP_OUT: RV12.1, U45.8 (output), U46.1 (input)
/ch12/FE: C123.1, J46.1 (In), R201.2, R202.2
/ch12/N_filt: C122.1, R199.2, R200.2, R201.1, R202.1
/ch12/OUT_50: J48.1 (In), R213.2
/ch12/PZ: RV12.2, RV12.3, U46.2 (P/Z)
/ch12/SHAPER_OUT: R210.2, R216.1, U47.8 (output), U48.3 (+)
/ch12/SHVN: C128.1, R207.2, U46.4 (-Vs)
/ch12/SHVP: C127.1, R206.2, U46.5 (+Vs)
/ch12/SH_OUT: R210.1, U46.8 (output), U47.1 (input)
/ch12/TEST_IN: C124.1, J47.1 (In), R203.1
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

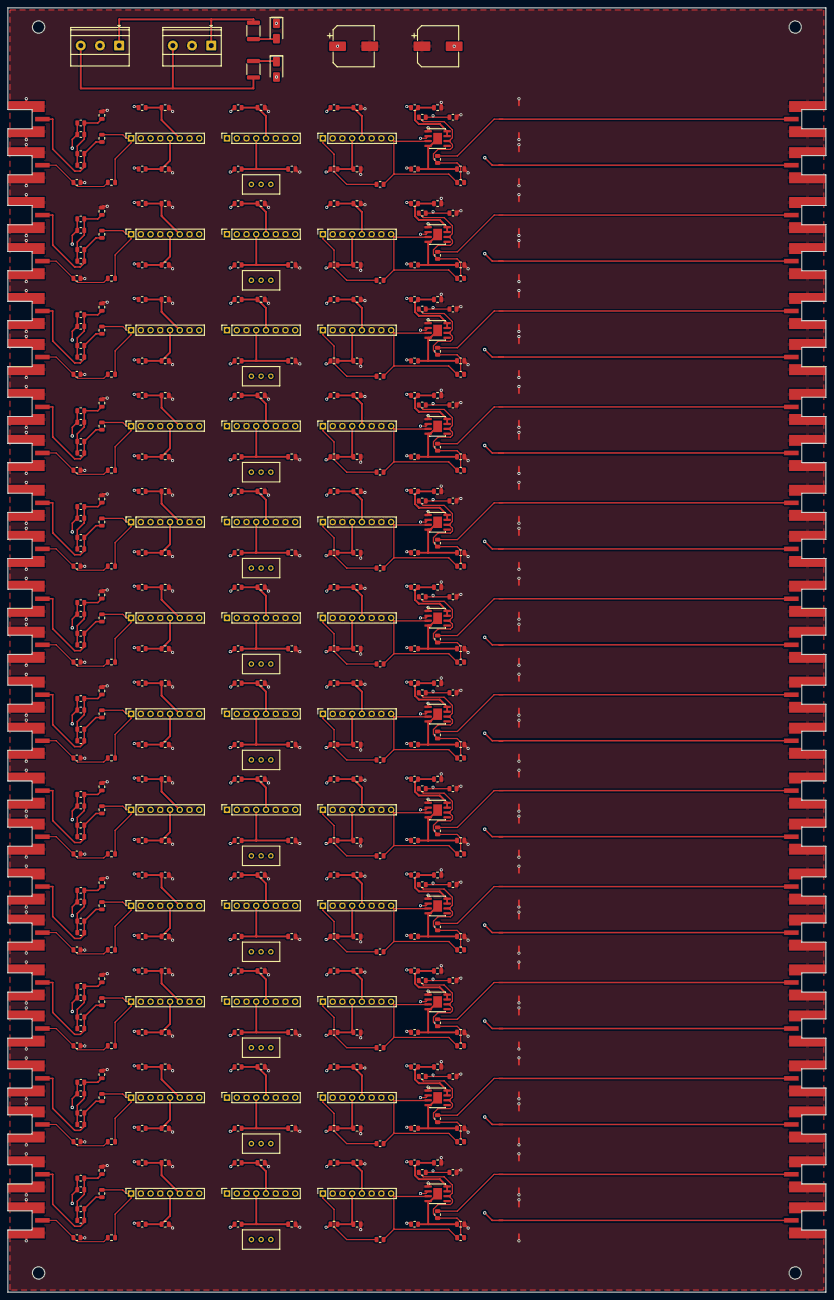
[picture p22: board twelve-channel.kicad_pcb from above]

Board: 4 copper layers, 213.2 x 334.7 mm, 468 parts (0 on the bottom side), 247 nets.

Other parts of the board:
H1, H2, H3, H4: MountingHole_3.2mm_M3

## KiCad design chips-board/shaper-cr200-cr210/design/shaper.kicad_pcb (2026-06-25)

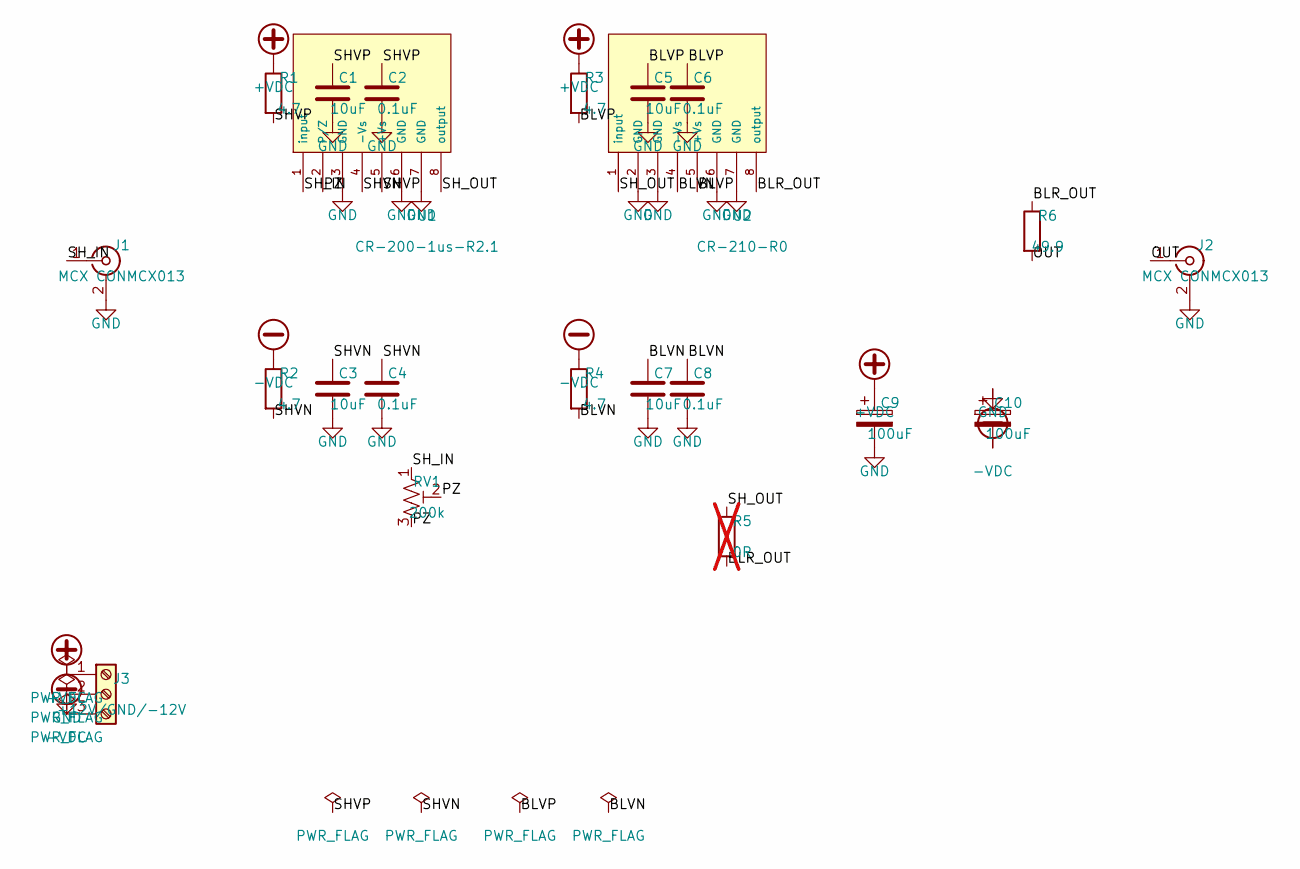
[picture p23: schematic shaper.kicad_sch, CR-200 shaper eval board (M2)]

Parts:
C1, C3, C5, C7: 10uF; C_0805_2012Metric; MPN CL21A106KAYNNNE
C2, C4, C6, C8: 0.1uF; C_0805_2012Metric; MPN CL21B104KBCNNNC
C9, C10: 100uF; CP_Elec_6.3x7.7; MPN UWT1V101MCL1GS
J1, J2: MCX CONMCX013; MCX_CONMCX013_EdgeMount; MPN CONMCX013
J3: +12V/GND/-12V; TerminalBlock_Phoenix_MKDS-1,5-3_1x03_P5.00mm_Horizontal; MPN 1715734
R1, R2, R3, R4: 4.7; R_0805_2012Metric; MPN RC0805JR-074R7L
R5: 0R; R_0805_2012Metric; MPN RC0805JR-070RL; not fitted
R6: 49.9; R_0805_2012Metric; MPN RC0805FR-0749R9L
RV1: 200k; Potentiometer_Bourns_3296W_Vertical; MPN 3296W-1-204LF
U1: CR-200-1us-R2.1; PinHeader_1x08_P2.54mm_Vertical; MPN CR-200-1us-R2.1
U2: CR-210-R0; PinHeader_1x08_P2.54mm_Vertical; MPN CR-210-R0

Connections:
+VDC: C9.1, J3.1, R1.1, R3.1
-VDC: C10.2, J3.3, R2.1, R4.1
BLR_OUT: R5.2, R6.1, U2.8 (output)
BLVN: C7.1, C8.1, R4.2, U2.4 (-Vs)
BLVP: C5.1, C6.1, R3.2, U2.5 (+Vs)
GND: C1.2, C2.2, C3.2, C4.2, C5.2, C6.2, C7.2, C8.2, C9.2, C10.1, J1.2 (Ext), J2.2 (Ext), J3.2, U1.3 (GND), U1.6 (GND), U1.7 (GND), U2.2 (GND), U2.3 (GND), U2.6 (GND), U2.7 (GND)
OUT: J2.1 (In), R6.2
PZ: RV1.2, RV1.3, U1.2 (P/Z)
SHVN: C3.1, C4.1, R2.2, U1.4 (-Vs)
SHVP: C1.1, C2.1, R1.2, U1.5 (+Vs)
SH_IN: J1.1 (In), RV1.1, U1.1 (input)
SH_OUT: R5.1, U1.8 (output), U2.1 (input)

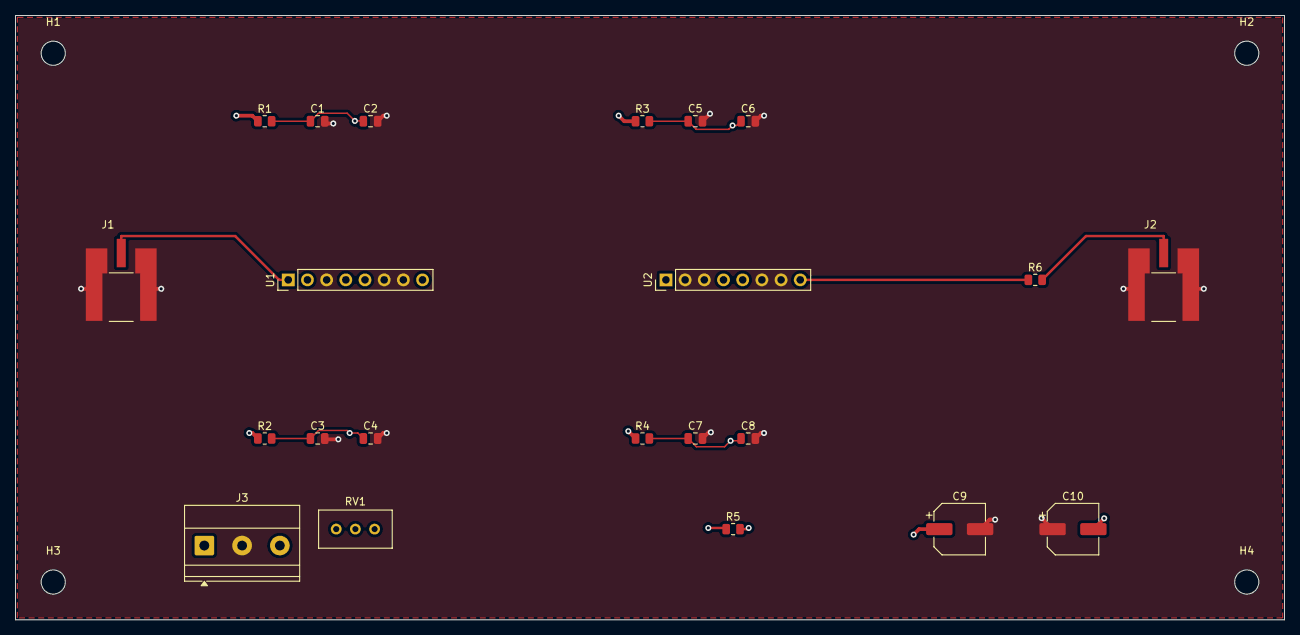
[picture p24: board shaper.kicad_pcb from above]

Board: 4 copper layers, 168.0 x 80.0 mm, 26 parts (0 on the bottom side), 12 nets.

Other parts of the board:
H1, H2, H3, H4: MountingHole_3.2mm_M3

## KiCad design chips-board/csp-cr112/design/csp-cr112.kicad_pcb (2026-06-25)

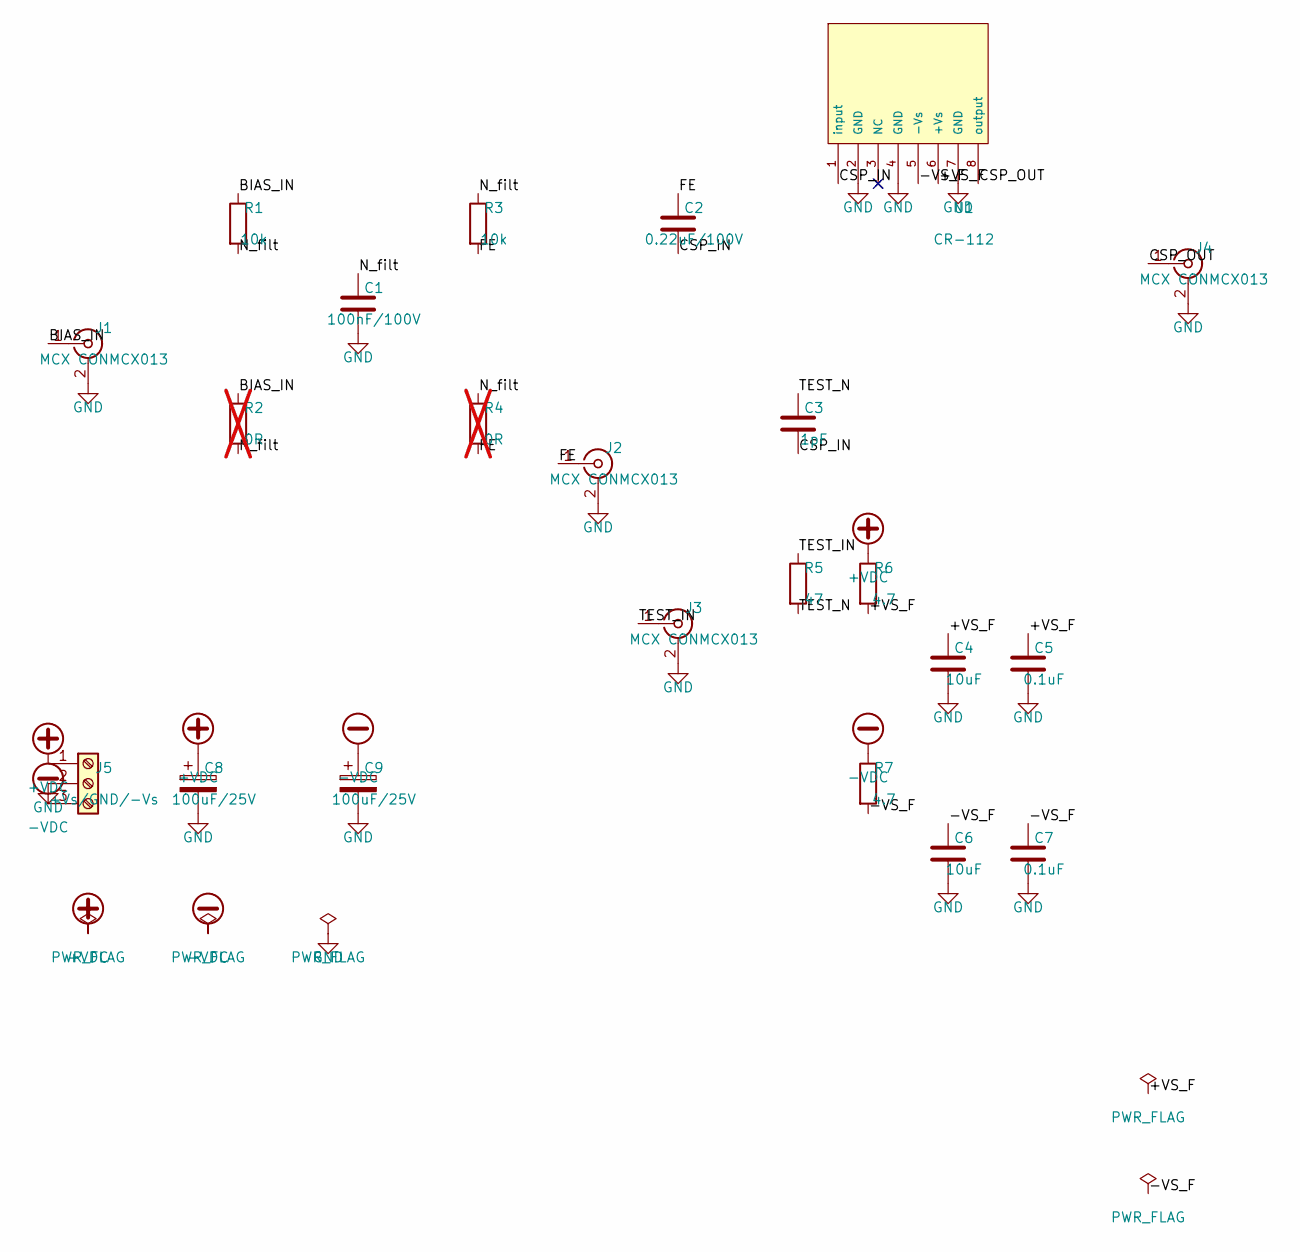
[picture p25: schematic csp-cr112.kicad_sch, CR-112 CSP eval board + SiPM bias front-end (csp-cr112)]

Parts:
C1: 100nF/100V; C_0805_2012Metric; MPN CL21B104KCC5PNC
C2: 0.22uF/100V; C_0805_2012Metric; MPN GRM21AR72A224KAC5K
C3: 1pF; C_0805_2012Metric; MPN CC0805CRNPO9BN1R0
C4, C6: 10uF; C_0805_2012Metric; MPN CL21A106KAYNNNE
C5, C7: 0.1uF; C_0805_2012Metric; MPN CL21B104KBCNNNC
C8, C9: 100uF/25V; CP_Radial_D6.3mm_P2.50mm; MPN UVR1E101MED
J1, J2, J3, J4: MCX CONMCX013; MCX_CONMCX013_EdgeMount; MPN CONMCX013
J5: +Vs/GND/-Vs; TerminalBlock_Phoenix_MKDS-1,5-3_1x03_P5.00mm_Horizontal; MPN 1715035
R1, R3: 10k; R_0805_2012Metric; MPN RC0805FR-0710KL
R2, R4: 0R; R_0805_2012Metric; MPN RC0805JR-070RL; not fitted
R5: 47; R_0805_2012Metric; MPN RC0805JR-0747RL
R6, R7: 4.7; R_0805_2012Metric; MPN RC0805JR-074R7L
U1: CR-112; PinHeader_1x08_P2.54mm_Vertical; MPN CR-112-R2.1

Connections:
+VDC: C8.1, J5.1, R6.1
-VDC: C9.1, J5.3, R7.1
/+VS_F: C4.1, C5.1, R6.2, U1.6 (+Vs)
/-VS_F: C6.1, C7.1, R7.2, U1.5 (-Vs)
/BIAS_IN: J1.1 (In), R1.1, R2.1
/CSP_IN: C2.2, C3.2, U1.1 (input)
/CSP_OUT: J4.1 (In), U1.8 (output)
/FE: C2.1, J2.1 (In), R3.2, R4.2
/N_filt: C1.1, R1.2, R2.2, R3.1, R4.1
/TEST_IN: J3.1 (In), R5.1
/TEST_N: C3.1, R5.2
GND: C1.2, C4.2, C5.2, C6.2, C7.2, C8.2, C9.2, J1.2 (Ext), J2.2 (Ext), J3.2 (Ext), J4.2 (Ext), J5.2, U1.2 (GND), U1.4 (GND), U1.7 (GND)

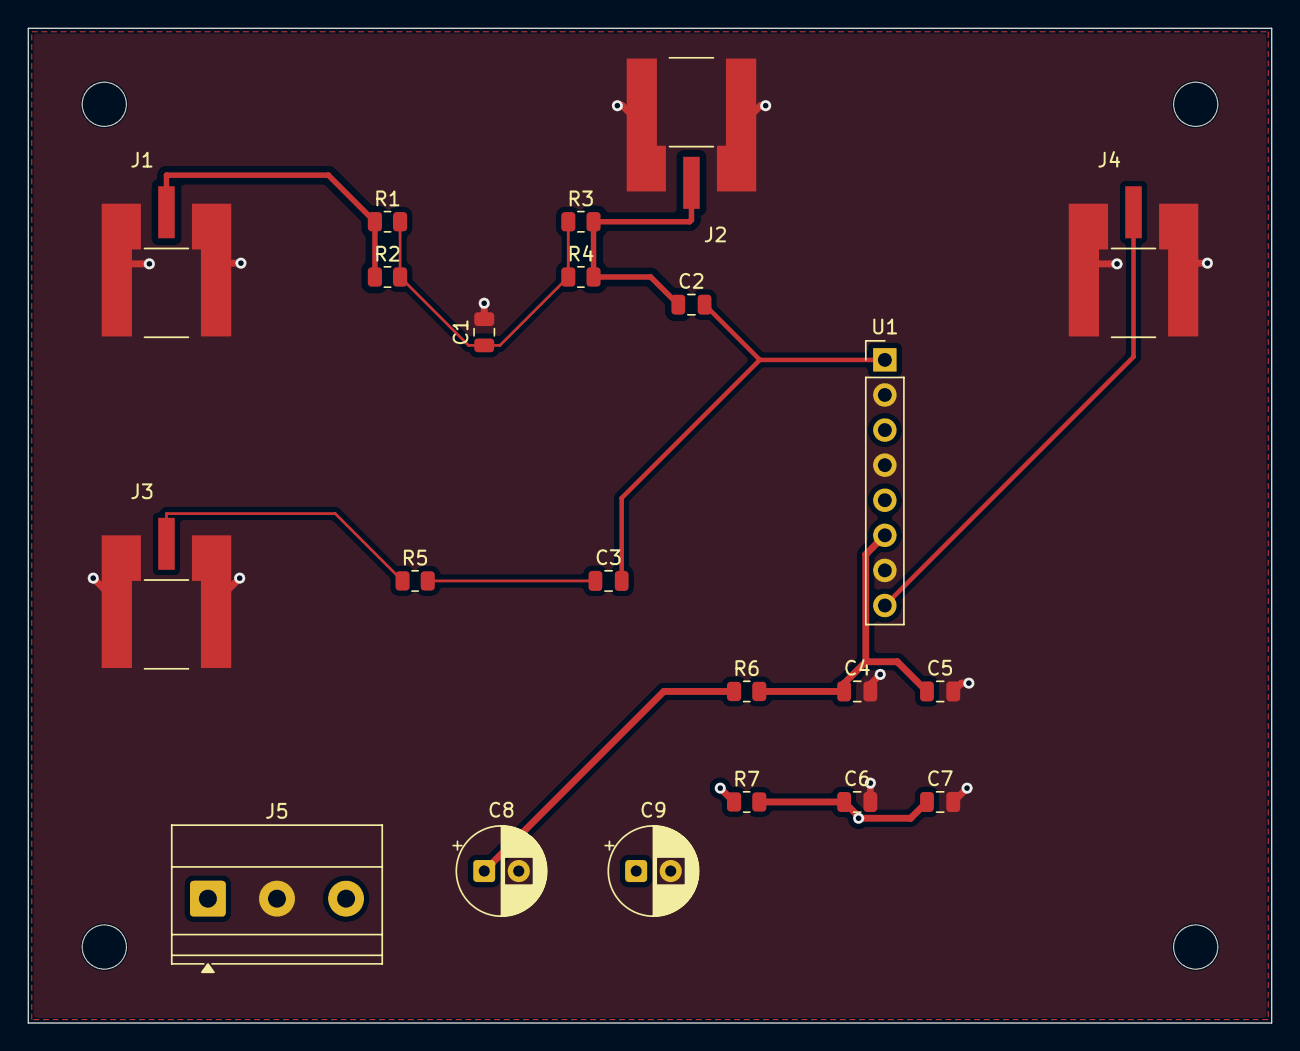
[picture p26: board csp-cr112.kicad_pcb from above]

Board: 4 copper layers, 90.0 x 72.0 mm, 26 parts (0 on the bottom side), 12 nets.

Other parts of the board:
H1, H2, H3, H4: MountingHole_3.2mm_M3

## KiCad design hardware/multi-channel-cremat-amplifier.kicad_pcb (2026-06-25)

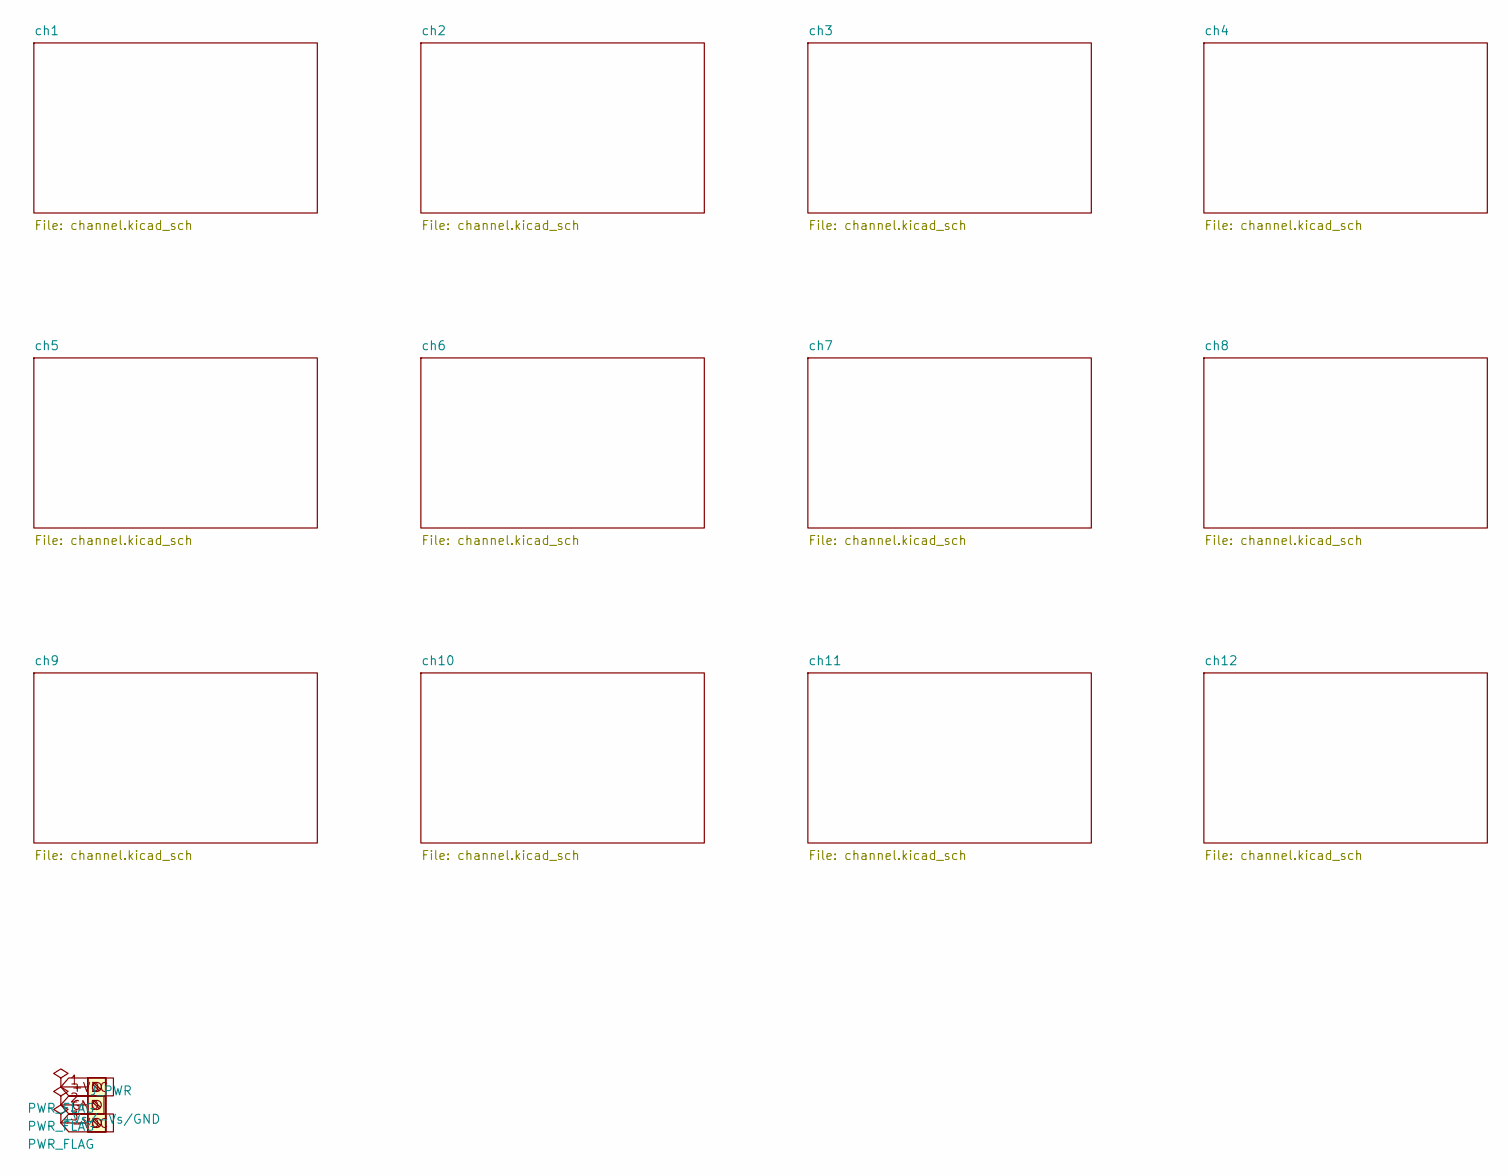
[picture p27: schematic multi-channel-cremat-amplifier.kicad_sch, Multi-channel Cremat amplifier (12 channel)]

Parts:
J_PWR: +Vs/-Vs/GND; TerminalBlock_Phoenix_MKDS-1,5-3_1x03_P5.00mm_Horizontal

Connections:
+VDC: J_PWR.1; also elsewhere on the board
-VDC: J_PWR.3; also elsewhere on the board
GND: J_PWR.2; also elsewhere on the board

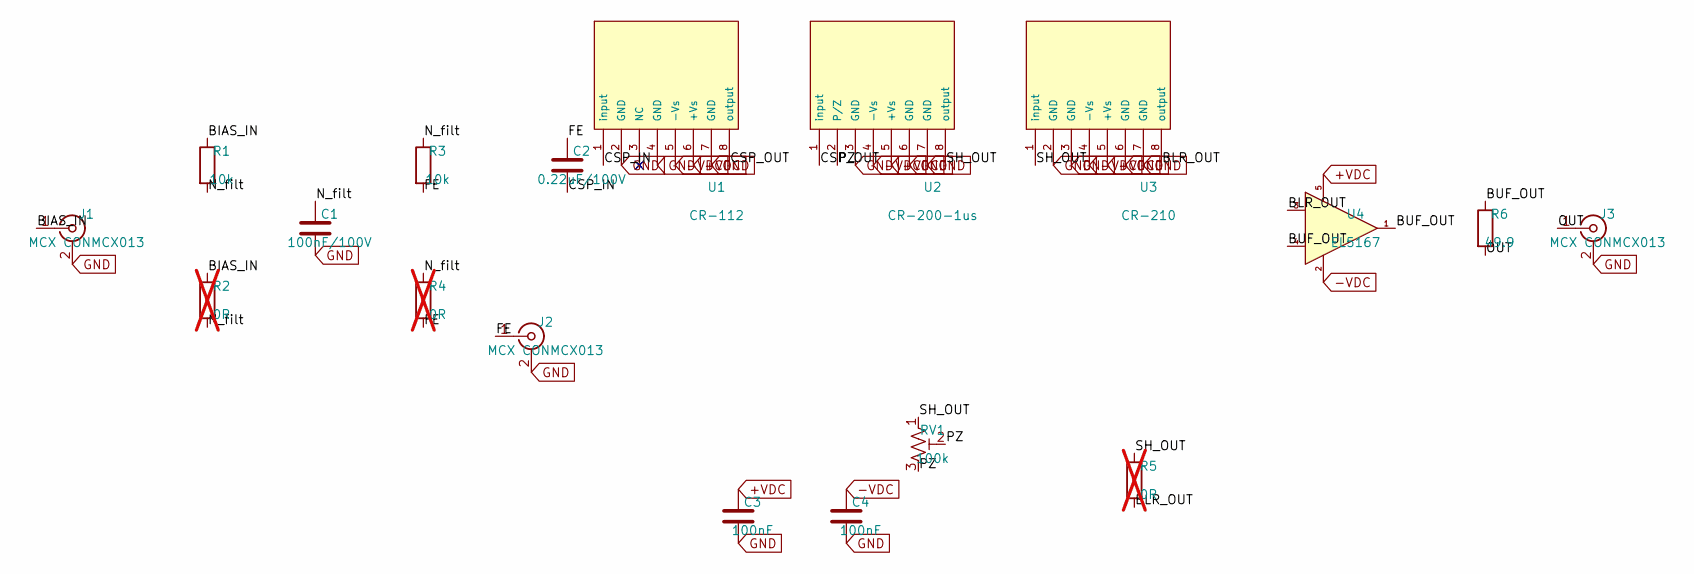
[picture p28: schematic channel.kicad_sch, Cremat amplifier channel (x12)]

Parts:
C1: 100nF/100V; C_0805_2012Metric
C2: 0.22uF/100V; C_0805_2012Metric
C3, C4: 100nF; C_0805_2012Metric
J1, J2, J3: MCX CONMCX013; MCX_CONMCX013_EdgeMount
R1, R3: 10k; R_0805_2012Metric
R2, R4, R5: 0R; R_0805_2012Metric; not fitted
R6: 49.9; R_0805_2012Metric
RV1: 100k; Potentiometer_Bourns_3296W_Vertical
U1: CR-112; PinHeader_1x08_P2.54mm_Vertical
U2: CR-200-1us; PinHeader_1x08_P2.54mm_Vertical
U3: CR-210; PinHeader_1x08_P2.54mm_Vertical
U4: EL5167; SOT-23-5

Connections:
+VDC: C3.1, U1.6 (+Vs), U2.5 (+Vs), U3.5 (+Vs), U4.5 (V+); also elsewhere on the board
-VDC: C4.1, U1.5 (-Vs), U2.4 (-Vs), U3.4 (-Vs), U4.2 (V-); also elsewhere on the board
/ch1/BIAS_IN: J1.1 (In), R1.1, R2.1
/ch1/BLR_OUT: R5.2, U3.8 (output), U4.3 (+)
/ch1/BUF_OUT: R6.1, U4.1, U4.4 (-)
/ch1/CSP_IN: C2.2, U1.1 (input)
/ch1/CSP_OUT: U1.8 (output), U2.1 (input)
/ch1/FE: C2.1, J2.1 (In), R3.2, R4.2
/ch1/N_filt: C1.1, R1.2, R2.2, R3.1, R4.1
/ch1/OUT: J3.1 (In), R6.2
/ch1/PZ: RV1.2, RV1.3, U2.2 (P/Z)
/ch1/SH_OUT: R5.1, RV1.1, U2.8 (output), U3.1 (input)
GND: C1.2, C3.2, C4.2, J1.2 (Ext), J2.2 (Ext), J3.2 (Ext), U1.2 (GND), U1.4 (GND), U1.7 (GND), U2.3 (GND), U2.6 (GND), U2.7 (GND), U3.2 (GND), U3.3 (GND), U3.6 (GND), U3.7 (GND); also elsewhere on the board

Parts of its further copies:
C5, C9, C13, C17, C21, C25, C29, C33, C37, C41, C45: 100nF/100V; C_0805_2012Metric
C6, C10, C14, C18, C22, C26, C30, C34, C38, C42, C46: 0.22uF/100V; C_0805_2012Metric
C7, C8, C11, C12, C15, C16, C19, C20, C23, C24, C27, C28, C31, C32, C35, C36, C39, C40, C43, C44, C47, C48: 100nF; C_0805_2012Metric
J4, J5, J6, J7, J8, J9, J10, J11, J12, J13, J14, J15, J16, J17, J18, J19, J20, J21, J22, J23, J24, J25, J26, J27, J28, J29, J30, J31, J32, J33, J34, J35, J36: MCX CONMCX013; MCX_CONMCX013_EdgeMount
R7, R9, R13, R15, R19, R21, R25, R27, R31, R33, R37, R39, R43, R45, R49, R51, R55, R57, R61, R63, R67, R69: 10k; R_0805_2012Metric
R8, R10, R11, R14, R16, R17, R20, R22, R23, R26, R28, R29, R32, R34, R35, R38, R40, R41, R44, R46, R47, R50, R52, R53, R56, R58, R59, R62, R64, R65, R68, R70, R71: 0R; R_0805_2012Metric; not fitted
R12, R18, R24, R30, R36, R42, R48, R54, R60, R66, R72: 49.9; R_0805_2012Metric
RV2, RV3, RV4, RV5, RV6, RV7, RV8, RV9, RV10, RV11, RV12: 100k; Potentiometer_Bourns_3296W_Vertical
U5, U9, U13, U17, U21, U25, U29, U33, U37, U41, U45: CR-112; PinHeader_1x08_P2.54mm_Vertical
U6, U10, U14, U18, U22, U26, U30, U34, U38, U42, U46: CR-200-1us; PinHeader_1x08_P2.54mm_Vertical
U7, U11, U15, U19, U23, U27, U31, U35, U39, U43, U47: CR-210; PinHeader_1x08_P2.54mm_Vertical
U8, U12, U16, U20, U24, U28, U32, U36, U40, U44, U48: EL5167; SOT-23-5

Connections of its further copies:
+VDC: C7.1, C11.1, C15.1, C19.1, C23.1, C27.1, C31.1, C35.1, C39.1, C43.1, C47.1, U5.6 (+Vs), U6.5 (+Vs), U7.5 (+Vs), U8.5 (V+), U9.6 (+Vs), U10.5 (+Vs), U11.5 (+Vs), U12.5 (V+), U13.6 (+Vs), U14.5 (+Vs), U15.5 (+Vs), U16.5 (V+), U17.6 (+Vs), U18.5 (+Vs), U19.5 (+Vs), U20.5 (V+), U21.6 (+Vs), U22.5 (+Vs), U23.5 (+Vs), U24.5 (V+), U25.6 (+Vs), U26.5 (+Vs), U27.5 (+Vs), U28.5 (V+), U29.6 (+Vs), U30.5 (+Vs), U31.5 (+Vs), U32.5 (V+), U33.6 (+Vs), U34.5 (+Vs), U35.5 (+Vs), U36.5 (V+), U37.6 (+Vs), U38.5 (+Vs), U39.5 (+Vs), U40.5 (V+), U41.6 (+Vs), U42.5 (+Vs), U43.5 (+Vs), U44.5 (V+), U45.6 (+Vs), U46.5 (+Vs), U47.5 (+Vs), U48.5 (V+); also elsewhere on the board
-VDC: C8.1, C12.1, C16.1, C20.1, C24.1, C28.1, C32.1, C36.1, C40.1, C44.1, C48.1, U5.5 (-Vs), U6.4 (-Vs), U7.4 (-Vs), U8.2 (V-), U9.5 (-Vs), U10.4 (-Vs), U11.4 (-Vs), U12.2 (V-), U13.5 (-Vs), U14.4 (-Vs), U15.4 (-Vs), U16.2 (V-), U17.5 (-Vs), U18.4 (-Vs), U19.4 (-Vs), U20.2 (V-), U21.5 (-Vs), U22.4 (-Vs), U23.4 (-Vs), U24.2 (V-), U25.5 (-Vs), U26.4 (-Vs), U27.4 (-Vs), U28.2 (V-), U29.5 (-Vs), U30.4 (-Vs), U31.4 (-Vs), U32.2 (V-), U33.5 (-Vs), U34.4 (-Vs), U35.4 (-Vs), U36.2 (V-), U37.5 (-Vs), U38.4 (-Vs), U39.4 (-Vs), U40.2 (V-), U41.5 (-Vs), U42.4 (-Vs), U43.4 (-Vs), U44.2 (V-), U45.5 (-Vs), U46.4 (-Vs), U47.4 (-Vs), U48.2 (V-); also elsewhere on the board
/ch2/BIAS_IN: J4.1 (In), R7.1, R8.1
/ch2/BLR_OUT: R11.2, U7.8 (output), U8.3 (+)
/ch2/BUF_OUT: R12.1, U8.1, U8.4 (-)
/ch2/CSP_IN: C6.2, U5.1 (input)
/ch2/CSP_OUT: U5.8 (output), U6.1 (input)
/ch2/FE: C6.1, J5.1 (In), R9.2, R10.2
/ch2/N_filt: C5.1, R7.2, R8.2, R9.1, R10.1
/ch2/OUT: J6.1 (In), R12.2
/ch2/PZ: RV2.2, RV2.3, U6.2 (P/Z)
/ch2/SH_OUT: R11.1, RV2.1, U6.8 (output), U7.1 (input)
/ch3/BIAS_IN: J7.1 (In), R13.1, R14.1
/ch3/BLR_OUT: R17.2, U11.8 (output), U12.3 (+)
/ch3/BUF_OUT: R18.1, U12.1, U12.4 (-)
/ch3/CSP_IN: C10.2, U9.1 (input)
/ch3/CSP_OUT: U9.8 (output), U10.1 (input)
/ch3/FE: C10.1, J8.1 (In), R15.2, R16.2
/ch3/N_filt: C9.1, R13.2, R14.2, R15.1, R16.1
/ch3/OUT: J9.1 (In), R18.2
/ch3/PZ: RV3.2, RV3.3, U10.2 (P/Z)
/ch3/SH_OUT: R17.1, RV3.1, U10.8 (output), U11.1 (input)
/ch4/BIAS_IN: J10.1 (In), R19.1, R20.1
/ch4/BLR_OUT: R23.2, U15.8 (output), U16.3 (+)
/ch4/BUF_OUT: R24.1, U16.1, U16.4 (-)
/ch4/CSP_IN: C14.2, U13.1 (input)
/ch4/CSP_OUT: U13.8 (output), U14.1 (input)
/ch4/FE: C14.1, J11.1 (In), R21.2, R22.2
/ch4/N_filt: C13.1, R19.2, R20.2, R21.1, R22.1
/ch4/OUT: J12.1 (In), R24.2
/ch4/PZ: RV4.2, RV4.3, U14.2 (P/Z)
/ch4/SH_OUT: R23.1, RV4.1, U14.8 (output), U15.1 (input)
/ch5/BIAS_IN: J13.1 (In), R25.1, R26.1
/ch5/BLR_OUT: R29.2, U19.8 (output), U20.3 (+)
/ch5/BUF_OUT: R30.1, U20.1, U20.4 (-)
/ch5/CSP_IN: C18.2, U17.1 (input)
/ch5/CSP_OUT: U17.8 (output), U18.1 (input)
/ch5/FE: C18.1, J14.1 (In), R27.2, R28.2
/ch5/N_filt: C17.1, R25.2, R26.2, R27.1, R28.1
/ch5/OUT: J15.1 (In), R30.2
/ch5/PZ: RV5.2, RV5.3, U18.2 (P/Z)
/ch5/SH_OUT: R29.1, RV5.1, U18.8 (output), U19.1 (input)
/ch6/BIAS_IN: J16.1 (In), R31.1, R32.1
/ch6/BLR_OUT: R35.2, U23.8 (output), U24.3 (+)
/ch6/BUF_OUT: R36.1, U24.1, U24.4 (-)
/ch6/CSP_IN: C22.2, U21.1 (input)
/ch6/CSP_OUT: U21.8 (output), U22.1 (input)
/ch6/FE: C22.1, J17.1 (In), R33.2, R34.2
/ch6/N_filt: C21.1, R31.2, R32.2, R33.1, R34.1
/ch6/OUT: J18.1 (In), R36.2
/ch6/PZ: RV6.2, RV6.3, U22.2 (P/Z)
/ch6/SH_OUT: R35.1, RV6.1, U22.8 (output), U23.1 (input)
/ch7/BIAS_IN: J19.1 (In), R37.1, R38.1
/ch7/BLR_OUT: R41.2, U27.8 (output), U28.3 (+)
/ch7/BUF_OUT: R42.1, U28.1, U28.4 (-)
/ch7/CSP_IN: C26.2, U25.1 (input)
/ch7/CSP_OUT: U25.8 (output), U26.1 (input)
/ch7/FE: C26.1, J20.1 (In), R39.2, R40.2
/ch7/N_filt: C25.1, R37.2, R38.2, R39.1, R40.1
/ch7/OUT: J21.1 (In), R42.2
/ch7/PZ: RV7.2, RV7.3, U26.2 (P/Z)
/ch7/SH_OUT: R41.1, RV7.1, U26.8 (output), U27.1 (input)
/ch8/BIAS_IN: J22.1 (In), R43.1, R44.1
/ch8/BLR_OUT: R47.2, U31.8 (output), U32.3 (+)
/ch8/BUF_OUT: R48.1, U32.1, U32.4 (-)
/ch8/CSP_IN: C30.2, U29.1 (input)
/ch8/CSP_OUT: U29.8 (output), U30.1 (input)
/ch8/FE: C30.1, J23.1 (In), R45.2, R46.2
/ch8/N_filt: C29.1, R43.2, R44.2, R45.1, R46.1
/ch8/OUT: J24.1 (In), R48.2
/ch8/PZ: RV8.2, RV8.3, U30.2 (P/Z)
/ch8/SH_OUT: R47.1, RV8.1, U30.8 (output), U31.1 (input)
/ch9/BIAS_IN: J25.1 (In), R49.1, R50.1
/ch9/BLR_OUT: R53.2, U35.8 (output), U36.3 (+)
/ch9/BUF_OUT: R54.1, U36.1, U36.4 (-)
/ch9/CSP_IN: C34.2, U33.1 (input)
/ch9/CSP_OUT: U33.8 (output), U34.1 (input)
/ch9/FE: C34.1, J26.1 (In), R51.2, R52.2
/ch9/N_filt: C33.1, R49.2, R50.2, R51.1, R52.1
/ch9/OUT: J27.1 (In), R54.2
/ch9/PZ: RV9.2, RV9.3, U34.2 (P/Z)
/ch9/SH_OUT: R53.1, RV9.1, U34.8 (output), U35.1 (input)
/ch10/BIAS_IN: J28.1 (In), R55.1, R56.1
/ch10/BLR_OUT: R59.2, U39.8 (output), U40.3 (+)
/ch10/BUF_OUT: R60.1, U40.1, U40.4 (-)
/ch10/CSP_IN: C38.2, U37.1 (input)
/ch10/CSP_OUT: U37.8 (output), U38.1 (input)
/ch10/FE: C38.1, J29.1 (In), R57.2, R58.2
/ch10/N_filt: C37.1, R55.2, R56.2, R57.1, R58.1
/ch10/OUT: J30.1 (In), R60.2
/ch10/PZ: RV10.2, RV10.3, U38.2 (P/Z)
/ch10/SH_OUT: R59.1, RV10.1, U38.8 (output), U39.1 (input)
/ch11/BIAS_IN: J31.1 (In), R61.1, R62.1
/ch11/BLR_OUT: R65.2, U43.8 (output), U44.3 (+)
/ch11/BUF_OUT: R66.1, U44.1, U44.4 (-)
/ch11/CSP_IN: C42.2, U41.1 (input)
/ch11/CSP_OUT: U41.8 (output), U42.1 (input)
/ch11/FE: C42.1, J32.1 (In), R63.2, R64.2
/ch11/N_filt: C41.1, R61.2, R62.2, R63.1, R64.1
/ch11/OUT: J33.1 (In), R66.2
/ch11/PZ: RV11.2, RV11.3, U42.2 (P/Z)
/ch11/SH_OUT: R65.1, RV11.1, U42.8 (output), U43.1 (input)
/ch12/BIAS_IN: J34.1 (In), R67.1, R68.1
/ch12/BLR_OUT: R71.2, U47.8 (output), U48.3 (+)
/ch12/BUF_OUT: R72.1, U48.1, U48.4 (-)
/ch12/CSP_IN: C46.2, U45.1 (input)
/ch12/CSP_OUT: U45.8 (output), U46.1 (input)
/ch12/FE: C46.1, J35.1 (In), R69.2, R70.2
/ch12/N_filt: C45.1, R67.2, R68.2, R69.1, R70.1
/ch12/OUT: J36.1 (In), R72.2
/ch12/PZ: RV12.2, RV12.3, U46.2 (P/Z)
/ch12/SH_OUT: R71.1, RV12.1, U46.8 (output), U47.1 (input)
GND: C5.2, C7.2, C8.2, C9.2, C11.2, C12.2, C13.2, C15.2, C16.2, C17.2, C19.2, C20.2, C21.2, C23.2, C24.2, C25.2, C27.2, C28.2, C29.2, C31.2, C32.2, C33.2, C35.2, C36.2, C37.2, C39.2, C40.2, C41.2, C43.2, C44.2, C45.2, C47.2, C48.2, J4.2 (Ext), J5.2 (Ext), J6.2 (Ext), J7.2 (Ext), J8.2 (Ext), J9.2 (Ext), J10.2 (Ext), J11.2 (Ext), J12.2 (Ext), J13.2 (Ext), J14.2 (Ext), J15.2 (Ext), J16.2 (Ext), J17.2 (Ext), J18.2 (Ext), J19.2 (Ext), J20.2 (Ext), J21.2 (Ext), J22.2 (Ext), J23.2 (Ext), J24.2 (Ext), J25.2 (Ext), J26.2 (Ext), J27.2 (Ext), J28.2 (Ext), J29.2 (Ext), J30.2 (Ext), J31.2 (Ext), J32.2 (Ext), J33.2 (Ext), J34.2 (Ext), J35.2 (Ext), J36.2 (Ext), U5.2 (GND), U5.4 (GND), U5.7 (GND), U6.3 (GND), U6.6 (GND), U6.7 (GND), U7.2 (GND), U7.3 (GND), U7.6 (GND), U7.7 (GND), U9.2 (GND), U9.4 (GND), U9.7 (GND), U10.3 (GND), U10.6 (GND), U10.7 (GND), U11.2 (GND), U11.3 (GND), U11.6 (GND), U11.7 (GND), U13.2 (GND), U13.4 (GND), U13.7 (GND), U14.3 (GND), U14.6 (GND), U14.7 (GND), U15.2 (GND), U15.3 (GND), U15.6 (GND), U15.7 (GND), U17.2 (GND), U17.4 (GND), U17.7 (GND), U18.3 (GND), U18.6 (GND), U18.7 (GND), U19.2 (GND), U19.3 (GND), U19.6 (GND), U19.7 (GND), U21.2 (GND), U21.4 (GND), U21.7 (GND), U22.3 (GND), U22.6 (GND), U22.7 (GND), U23.2 (GND), U23.3 (GND), U23.6 (GND), U23.7 (GND), U25.2 (GND), U25.4 (GND), U25.7 (GND), U26.3 (GND), U26.6 (GND), U26.7 (GND), U27.2 (GND), U27.3 (GND), U27.6 (GND), U27.7 (GND), U29.2 (GND), U29.4 (GND), U29.7 (GND), U30.3 (GND), U30.6 (GND), U30.7 (GND), U31.2 (GND), U31.3 (GND), U31.6 (GND), U31.7 (GND), U33.2 (GND), U33.4 (GND), U33.7 (GND), U34.3 (GND), U34.6 (GND), U34.7 (GND), U35.2 (GND), U35.3 (GND), U35.6 (GND), U35.7 (GND), U37.2 (GND), U37.4 (GND), U37.7 (GND), U38.3 (GND), U38.6 (GND), U38.7 (GND), U39.2 (GND), U39.3 (GND), U39.6 (GND), U39.7 (GND), U41.2 (GND), U41.4 (GND), U41.7 (GND), U42.3 (GND), U42.6 (GND), U42.7 (GND), U43.2 (GND), U43.3 (GND), U43.6 (GND), U43.7 (GND), U45.2 (GND), U45.4 (GND), U45.7 (GND), U46.3 (GND), U46.6 (GND), U46.7 (GND), U47.2 (GND), U47.3 (GND), U47.6 (GND), U47.7 (GND); also elsewhere on the board

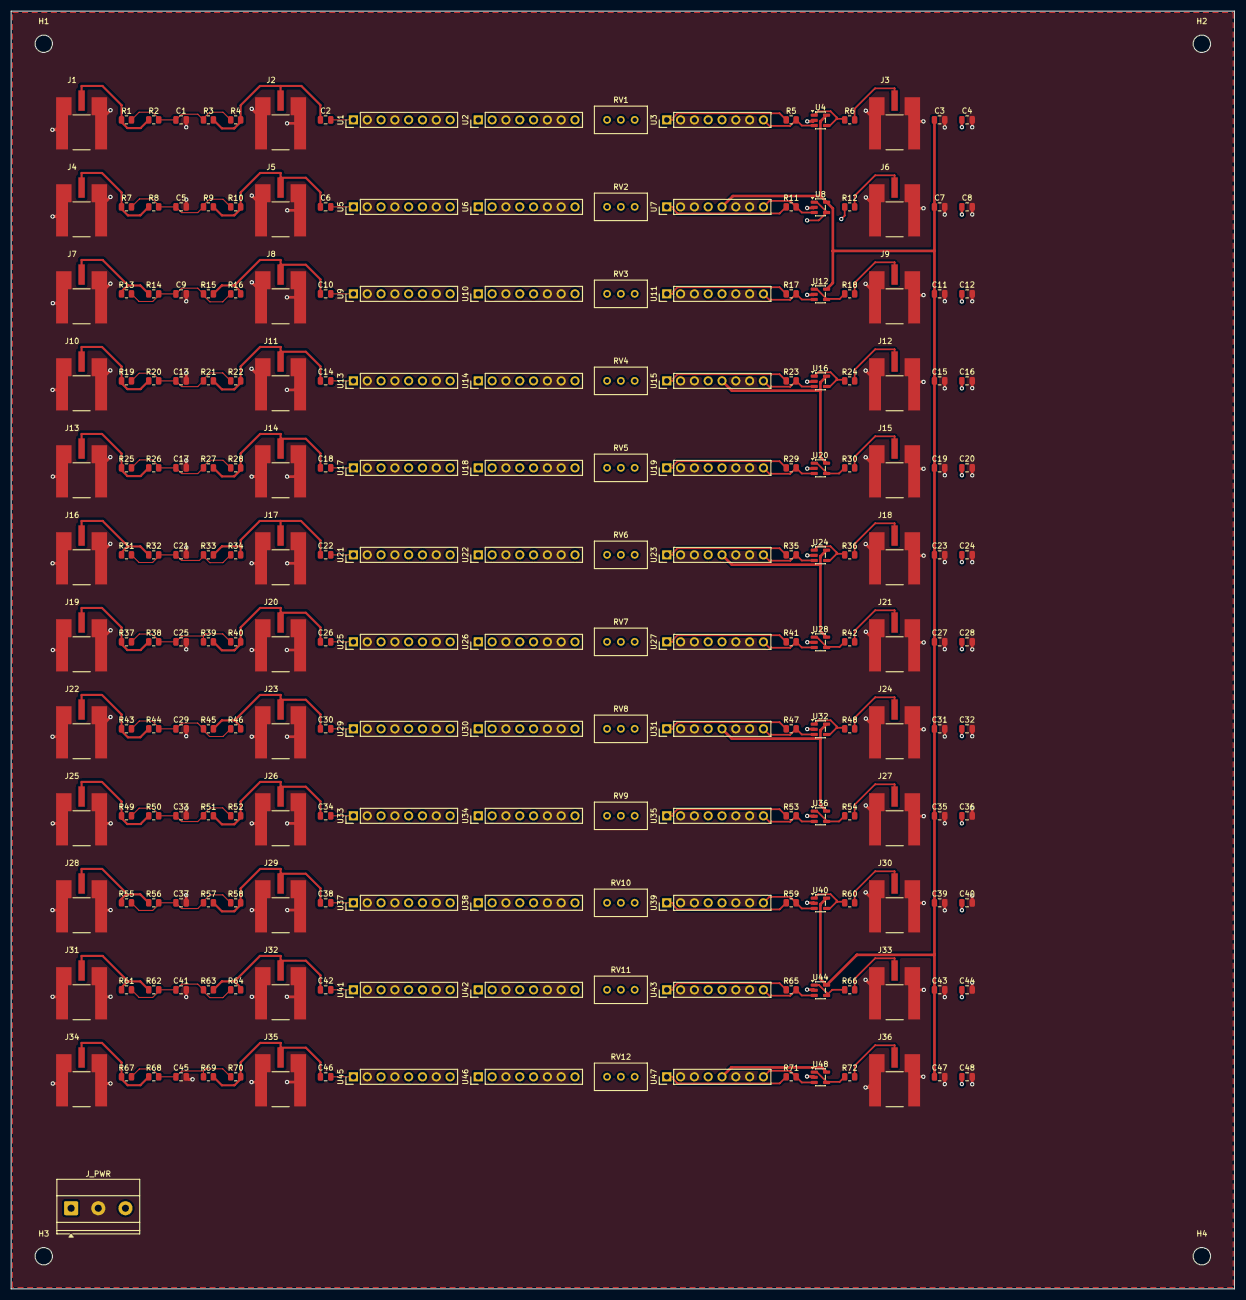
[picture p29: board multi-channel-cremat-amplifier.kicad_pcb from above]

Board: 4 copper layers, 225.0 x 235.0 mm, 221 parts (0 on the bottom side), 123 nets.

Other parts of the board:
H1, H2, H3, H4: MountingHole_3.2mm_M3

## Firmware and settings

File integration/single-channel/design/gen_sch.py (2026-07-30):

#!/usr/bin/env python3
"""Generate the single-channel board schematic (Phase B, track B1 chan-design).

Merges the two PROVEN Phase-A sub-components AS-IS and appends the output buffer:

  BIAS_IN/SIPM -> [csp-cr112 front-end + CR-112] --CSP_OUT--> [CR-200 + CR-210 shaper]
      --SHAPER_OUT--> [THS3491 CFA buffer, Av=+2] --49.9R--> OUT_50 (MCX, 50ohm back-term)

REVIEW LAYOUT (2026-07): this schematic is drawn for HUMAN REVIEW. Every part is placed
on a left->right signal spine with generous spacing (no overlaps), the signal path is
WIRED pin-to-pin, per-rail decoupling lives in a top (+rail) / bottom (-rail) band, and
power is distributed with power symbols + net labels the way an engineer would draw it.

DESIGN NOTES (2026-07, requested changes on top of the redraw):
  * Test input is a coax-terminated charge injector: J_TEST -> TEST_IN, R_test = shunt
    termination to GND, C_test couples TEST_IN straight into CSP_IN (R_test is NOT in series).
  * The output buffer is a POPULATE-OR-BYPASS block: JP_BUF (0R, SHAPER_OUT->BUF_OUT) XOR the
    THS3491 buffer. Default build = buffer DNP + JP_BUF fitted (shaper drives the 49.9 back-term
    directly). Populate the buffer (U_BUF/R_FB/R_GAIN + BVP/BVN decoupling) and remove JP_BUF for
    the +2 gain stage. R_BSER (49.9), J_OUT50 and JP_BUF stay fitted in both variants.
  * Rail protection = REVERSE-POLARITY block + fault interrupt (per rail): screw terminal ->
    resettable PTC (F_P/F_N, 100 mA hold) -> series Schottky (D_RP/D_RN, SS14, 40 V/1 A) -> board
    rail. The Schottky blocks a reversed supply (cathode-to-rail on +12, anode-to-rail on -12);
    the PTC interrupts a sustained fault. NO shunt over-voltage clamp: the Cremat modules'
    +/-13 V supply abs-max vs the +/-12 V nominal rail leaves no window for a passive clamp that
    both stays off at 12 V and holds below 13 V (verified vs CR-112/CR-200/CR-210 + THS3491
    datasheets), so over-voltage is an operational limit, not a clamp. New internal nets
    +VDC_F / -VDC_F sit between each PTC and its Schottky.

Method: place each symbol at a chosen (x, y, rotation); compute transformed pin
coordinates with a validated CCW transform (schematic Y-down); draw orthogonal wires
between pins; drop net labels on signal wires, power symbols on rails, no-connects on
NC pins. Deterministic uuid5 UUIDs so re-runs reproduce the file.

Run:  "C:/Program Files/KiCad/10.0/bin/python.exe" gen_sch.py
Validate: kicad-cli sch erc channel.kicad_sch ; kicad-cli sch export netlist ...
"""
import os, re, uuid, math

HERE = os.path.dirname(os.path.abspath(__file__))
CREMAT_SYM = os.path.join(HERE, "lib", "cremat.kicad_sym")
STOCK = r"C:/Program Files/KiCad/10.0/share/kicad/symbols"
PROJ = "channel"
NS = uuid.UUID("b1c2d3e4-0000-4000-8000-000000000000")   # B1-namespaced (distinct from A1/A4)
VERSION = "20250610"      # real KiCad-10 schematic format (the fictitious "20260306" made KiCad's GUI
                          # treat the file as newer-than-itself and load it degraded -> phantom parity fails)

def uid(*p): return str(uuid.uuid5(NS, ":".join(str(x) for x in p)))
def G(v): return round(round(float(v) / 1.27) * 1.27, 4)  # snap to 1.27mm connection grid

# ---------- minimal S-expression symbol-library reader (same as Phase-A scripts) ----------
def _match(text, start):
    depth, i, n = 0, start, len(text); in_str = False
    while i < n:
        c = text[i]
        if in_str:
            if c == '\\': i += 1
            elif c == '"': in_str = False
        elif c == '"': in_str = True
        elif c == '(': depth += 1
        elif c == ')':
            depth -= 1
            if depth == 0: return i + 1
        i += 1
    raise ValueError("unbalanced")

def extract_symbol(libtext, name):
    m = re.search(r'\(symbol\s+"%s"' % re.escape(name), libtext)
    if not m: raise KeyError(name)
    return libtext[m.start():_match(libtext, m.start())]

def pin_coords(block):
    out = {}
    for pm in re.finditer(r'\(pin\b', block):
        s = pm.start(); e = _match(block, s); sub = block[s:e]
        at = re.search(r'\(at\s+(-?[\d.]+)\s+(-?[\d.]+)\s+(-?[\d.]+)\)', sub)
        num = re.search(r'\(number\s+"([^"]+)"', sub)
        if at and num:
            out[num.group(1)] = (float(at.group(1)), float(at.group(2)))
    return out

_libcache = {}
def lib_text(path):
    if path not in _libcache:
        with open(path, encoding="utf-8") as f: _libcache[path] = f.read()
    return _libcache[path]

SYMSRC = {
    "cremat:CR-11X": (CREMAT_SYM, "CR-11X"),
    "cremat:CR-200": (CREMAT_SYM, "CR-200"),
    "cremat:CR-210": (CREMAT_SYM, "CR-210"),
    "cremat:THS3491xDDA": (CREMAT_SYM, "THS3491xDDA"),   # TI HV CFA output buffer (SOIC-8 PowerPAD)
    "Device:R": (f"{STOCK}/Device.kicad_sym", "R"),
    "Device:C": (f"{STOCK}/Device.kicad_sym", "C"),
    "Device:C_Polarized": (f"{STOCK}/Device.kicad_sym", "C_Polarized"),
    "Device:R_Potentiometer_Trim_US": (f"{STOCK}/Device.kicad_sym", "R_Potentiometer_Trim_US"),
    "Device:D_Schottky": (f"{STOCK}/Device.kicad_sym", "D_Schottky"),
    "Device:Polyfuse_Small": (f"{STOCK}/Device.kicad_sym", "Polyfuse_Small"),
    "Connector:Conn_Coaxial": (f"{STOCK}/Connector.kicad_sym", "Conn_Coaxial"),
    "Connector:Screw_Terminal_01x03": (f"{STOCK}/Connector.kicad_sym", "Screw_Terminal_01x03"),
    "power:+VDC": (f"{STOCK}/power.kicad_sym", "+VDC"),
    "power:-VDC": (f"{STOCK}/power.kicad_sym", "-VDC"),
    "power:GND": (f"{STOCK}/power.kicad_sym", "GND"),
    "power:PWR_FLAG": (f"{STOCK}/power.kicad_sym", "PWR_FLAG"),
}
_pins = {}
def pins_of(lib_id):
    if lib_id not in _pins:
        f, nm = SYMSRC[lib_id]
        _pins[lib_id] = pin_coords(extract_symbol(lib_text(f), nm))
    return _pins[lib_id]

def indent(s, n):
    pad = "\t" * n
    return "\n".join(pad + ln if ln else ln for ln in s.splitlines())

def lib_symbols_block():
    parts = []
    for lib_id, (f, nm) in SYMSRC.items():
        raw = extract_symbol(lib_text(f), nm)
        raw = raw.replace('(symbol "%s"' % nm, '(symbol "%s"' % lib_id, 1)
        parts.append(raw)
    body = "\n".join(indent(p, 2) for p in parts)
    return "\t(lib_symbols\n%s\n\t)" % body
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

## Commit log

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2026-06-24 Resolve build decisions D1-D6; correct BIAS_IN to per-channel
    Record the user's answers in docs/development-plan.md and propagate them
    through the spec:
    - D1: SiPM bias <= 60 V; keep Cc/Cf rated 100 V; hv_bias creepage ~1.0 mm.
    - D2/D3: ALL per-channel I/O is MCX edge-mount, TE Connectivity Linx
    CONMCX013 (DK 343-CONMCX013-ND) -- including BIAS_IN (not SHV).
    - D4: order CR-112 (CSP) + CR-200-1us (shaper); reference used CR-113.
    - D5: rack-mounted, two 12-ch boards side-by-side in one box; board width
    ~200-215 mm; all 36 MCX on the front edge.
    - D6: explained (first-build populate variant) -> default Full.
    Architecture correction (per user): BIAS_IN, SIPM, OUT are EACH per-channel
    -> 3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
2026-06-24 Track 2: front-end design for the Hamamatsu VUV4
    User supplied the target detector: Hamamatsu VUV4 MPPC (S13370, 6 mm /
    75 um), 45-55 V reverse bias, ~220 fC per V overvoltage, Cdet ~1.28 nF.
    Add docs/hardware/circuit-design.md (Track 2 deliverable) and lock the
    per-channel front-end values from first-order design:
    - Bias filter: Rf1=Rf2=10k, Cf=100nF/100V (fc~159 Hz); cold-only boards may
    raise Rf to 100k-1M. Cc=0.22uF/100V (>> Cdet -> ~99% charge transfer).
    - Polarity: SiPM cathode on the front-end node, +45..55 V; anode -> GND;
    positive bias supply.
    - CR-112 (13 mV/pC) confirmed appropriate; linear range ~200 p.e. @3.5V OV,
    with CR-113 as the lower-gain fallback.
    - Noise: SiPM gain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
2026-06-24 D5: rack box ~482 x 244 mm -> per-board outline ~225 x 235 mm
    Box is ~482 mm (19" rack) x 244 mm deep, two 12-ch boards side-by-side.
    Per-board outline budget ~225 (W) x 235 (D) mm after walls/divider/clearance.
    Flag the connector-density constraint: 36 board-edge MCX (CONMCX013, ~6.4 mm)
    do not fit single-row on a ~225 mm edge. Recommend a front/rear split --
    24 BIAS_IN+SIPM on the front edge (~9.4 mm pitch), 12 OUT on the rear
    (~19 mm) -- with two-row / per-channel-cluster alternatives noted.
    Rack U / front-panel height still TBD. Updated board.md, development-plan
    (D5 + Track 4), README, session-report.
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2026-06-24 Track 1: KiCad project skeleton, symbol library, lib tables, fielded BOM
    hardware/ now contains the real, kicad-cli-validated foundation for the build:
    - lib/cremat.kicad_sym: CR-11X (CR-112), CR-200, CR-210 (pin 2 = GND,
    confirmed from CR-160-R7), and the EL5167 buffer. Validated/canonicalized
    with `kicad-cli sym upgrade` (KiCad 10).
    - sym-lib-table / fp-lib-table: register the project lib via ${KIPRJMOD}.
    Stock KiCad libs cover 0805 R/C, SIP-8 (1x08 header), SOT-23-5, trimpots,
    screw terminal; lib/cremat.pretty holds the one to-create footprint.
    - lib/cremat.pretty/README.md: MCX CONMCX013 footprint flagged TO CREATE
    (datasheet-verified) rather than shipping wrong pad geometry.
    -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
    [bom-full-variant.csv]
2026-06-24 Tracks 3 & 4: integration-notes.md and mechanical.md deliverables
    - integration-notes.md (Track 3): the golden per-channel netlist — hierarchy
    (channel sheet x12 + power ports), confirmed SIP-8 pinouts, a net->pin
    table for every node, the two populate-XOR bypass jumpers, and capture
    notes (P/Z + buffer carry from the reference channel).
    - mechanical.md (Track 4): 1U open-tray enclosure, per-board outline
    ~225x235 mm, <35 mm height budget, the input-edge/output-edge 36x MCX
    placement, M3 standoff mounting, and the hv_bias clearance note.
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2026-06-24 Track 5: generate the 12-channel schematic headless (ERC 0 errors)
    Adopt the method in docs/KICAD_WITH_CLAUDE_CODE.md (Eeschema has no API, but
    .kicad_sch is text + kicad-cli is a headless validator). My earlier
    "schematic = GUI boundary" conclusion was wrong.
    hardware/gen_sch.py writes the schematic by placing every symbol at
    rotation 0 and dropping a net label (local, signal nets) or global label
    (rails) at the exact pin coordinate -- connectivity by net name, no routed
    wires -- with deterministic uuid5 UUIDs. It reuses the real symbol bodies
    from lib/cremat.kicad_sym + KiCad stock libs.
    Outputs (committed):
    - channel.kicad_sch one channel cell
    - multi-channel-cr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
    [channel.kicad_sch, multi-channel-cremat-amplifier.kicad_sch]
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2026-06-24 Track 6: pcbnew board scaffold (217 footprints + nets + outline + GND zone)
    hardware/gen_pcb.py builds the PCB headless from the netlist with KiCad's
    pcbnew Python API: loads + places all 217 footprints, assigns every net,
    draws the 225x235 mm Edge.Cuts outline + 4x M3 holes, adds an (unfilled)
    GND zone, and re-applies the project net classes (pcbnew's save resets them).
    Fixed J_PWR footprint name (_Horizontal) so all 217 place.
    Honest scope: pcbnew has NO autorouter. The board is a net-assigned starting
    point on a grid -- NOT routed and NOT a manufacturable arrangement (parts
    overlap; the edge-launch MCX cutouts must move to the board edge). Signal
    routing + final placement are the KiCad G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
    [bom-full-variant.csv, multi-channel-cremat-amplifier.kicad_pcb, multi-channel-cremat-amplifier.kicad_sch]
2026-06-24 Track 6: per-channel row placement + FreeRouting DSN/SES workflow
    Placement (gen_pcb.py): group the 12 channels into signal-ordered rows
    (J_BIAS | filter | J_SIPM+Cc | CR-11X | CR-200+P/Z | CR-210 | buffer |
    R_OUT | J_OUT), module-length-aware spacing; cut DRC errors 387->266.
    MCX Edge.Cuts moved to Dwgs.User (via SetLayer, not Remove -- Remove
    corrupts fp.Pads) so the outline stays one clean rectangle; re-cut edges
    in GUI when mechanically placing jacks.
    Autorouting workflow (KiCad has no autorouter):
    - hardware/export_dsn.py -> Specctra .dsn (pcbnew.ExportSpecctraDSN)
    - hardware/import_ses.py -> import routed .ses back to the board
    - docs/FREEROUTING.md -> download + GUI/CLI auto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
    [multi-channel-cremat-amplifier.kicad_pcb]
2026-06-25 Track 6: DRC-clean placement (bounding-box packed) + HV creepage fix
    Placement is now 0 DRC errors / 0 warnings (only the unrouted ratsnest
    remains). Fixes:
    - gen_pcb.py packs each channel as a left->right strip using real footprint
    bounding boxes (pcbnew GetBoundingBox), so nothing overlaps -- replaces the
    fixed-x guesswork that caused the overlaps.
    - SIP-8 modules are 21mm tall at rot0; rotate them 90deg to lie flat in the
    16mm row pitch.
    - Root cause of the 60 "clearance" errors: hv_bias netclass was 1.0mm, but a
    single 0805's own two pads are ~0.9mm apart, and the AC-coupling cap Cc
    bridges HV(FE)->amp(CSP_IN) across that 0.9mm. Set hv_bias clearance to
    0.6mm (IPC-2221 extern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
    [multi-channel-cremat-amplifier.kicad_pcb]
2026-06-25 Track 6: fill GND pour (fill_zones.py); board = clean placement + ground plane
    fill_zones.py fills zones on the loaded board (safe; in-memory fill during
    construction segfaults). Board state: DRC-clean placement + filled B.Cu GND
    pour (THT module GND pins tie to it); 480-item ratsnest remains (signals,
    power, SMD-GND vias unrouted).
    Tried naive straight-line signal routing -> it shorts (traces cut across
    other nets' pads: 146 shorting + 208 mask-bridge). Lesson: this board's
    component-chain traces need obstacle avoidance (an autorouter); the 25-ch
    fanout routed clean only because it was single straight traces. So routing =
    FreeRouting on the (now clean, DSN-exportable) board.
    Co-Authored-B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
    [multi-channel-cremat-amplifier.kicad_pcb]
2026-06-25 Track 6 DONE: fully autorouted 12-channel board, DRC 0/0/0
    Did the complete layout headless -- placement + routing + planes:
    - gen_pcb.py: 4-layer board, GND plane (In1) + -VDC plane (In2) so both
    outer layers are free to route; bbox-packed per-channel rows (DRC-clean
    placement).
    - export_dsn.py -> Specctra DSN -> FreeRouting v2.2.4 (Java 25) autoroutes
    all 480 nets (0 unrouted) -> import_ses.py -> routed .kicad_pcb.
    - fill_zones.py: fill GND/-VDC planes + add outer-layer GND ground-fill,
    solid pad connection (reconnects stray THT GND pads, no starved thermals).
    Final DRC: 0 errors, 0 warnings, 0 unconnected. 1070 track segments.
    Render: hardware/routed-top.png (12 clean channel row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
    [multi-channel-cremat-amplifier.kicad_pcb]
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2026-07-08 Single-channel: 2026-07 rework + rail reverse-polarity protection + doc reconcile
    Rail protection (per rail): screw terminal -> PTC (F1/F2, Littelfuse 1206L010/60WR)
    -> series Schottky (D1/D2, onsemi SS14) -> board rail. Blocks reversed supply leads and
    interrupts sustained faults. No over-voltage clamp: the +/-13 V Cremat module supply
    abs-max vs the +/-12 V nominal rail leaves no passive-clamp window (datasheet-verified,
    adversarially checked), so over-voltage is an operational limit. New nets
    +VDC_IN/+VDC_F/-VDC_IN/-VDC_F.
    Folds in the prior 2026-07 design rework:
    - Output buffer is now populate-or-bypass: THS3491 block DNP by default + JP_BUF 0R bypass
    (default build = CR-210 drives t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
    [channel.kicad_sch, single-channel-bom.csv]
2026-07-08 Single-channel PCB: rebuild as a thin, tile-able channel-row cell (DRC 0/0/0)
    Lay out channel.kicad_pcb per the requested floorplan: each channel is a horizontal ROW
    (signal left->right: front-end -> CR-112 -> CR-200 -> CR-210 -> THS3491), the four MCX
    edge-mount female jacks at the two SHORT ends (left = SIPM(IN)+TEST_IN, right = OUT_50+BIAS_IN),
    and a shared COM row across the top (screw terminal + F1/F2 PTC + D1/D2 Schottky + C10/C11 bulk,
    power in at the rear). Channels stack below the COM row for the multi-channel board. Thin:
    138 x 52 mm (the stacked MCX-pair height sets the ~24 mm channel row).
    - gen_pcb.py: new PLACE / W,H / DNP_BY_REF for the floorplan + the 2026-07 refs (F1/F2/D1/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
    [channel.kicad_pcb]
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2026-07-08 Sourcing: swap 10uF bulk to in-stock KEMET C0805C106K3PACTU
    The fitted 10uF 25V X5R 0805 bulk (x8 decoupling caps) was the 0-stock Samsung
    CL21A106KAYNNNE (Active, 29-wk lead). Swapped to the in-stock KEMET C0805C106K3PACTU
    (DK 399-11939-1-ND) - re-verified live: ~255k stock, Active, $0.23 q1 / $0.083 q100,
    exact 0805 drop-in. Beat Taiyo Yuden (in stock but ~600 pcs), TDK (stocked but NRND),
    Murata/Yageo (0-stock). Samsung kept as documented alternate (same-mfr fallback
    CL21A106KACLRNC ~71k). Value-only swap in gen_sch.py (8 caps) + 8 BOM rows; 0805 footprint
    and PCB unchanged; schematic ERC 0/0. Docs updated (INTERFACE, SESSION_REPORT/LOG, sourcing).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
    [channel.kicad_sch, single-channel-bom.csv]
2026-07-08 Fix: link PCB footprints to schematic-symbol UUIDs (Update-from-Sch re-spawned parts)
    The headless-built board's footprints carried no symbol UUID in their (path ...), so KiCad's
    'Update PCB from Schematic' matched nothing and re-added a duplicate of every footprint.
    gen_pcb.py now writes each footprint's UUID from the netlist (fp.SetPath) and marks mounting
    holes board-only; the same was applied in place to the committed routed board - no re-route,
    so DRC stays 0/0/0 and the routes are intact. Also gitignore KiCad _autosave-* files.
    To apply on an open project: close without saving + git pull; OR re-run Update PCB from
    Schematic with 're-link footprints by reference designators' checked (w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
    [channel.kicad_pcb]
2026-07-08 12-channel schematic: hierarchical (channel sheet x12) + daisy power, ERC 0
    Rebuilt final-board/twelve-channel from the reworked single channel as a KiCad HIERARCHICAL
    design (matches CLAUDE.md 'per-channel sheet instantiated 12x' + the x6 reference):
    * channel.kicad_sch = the reviewed single channel MINUS board power entry; every symbol
    placed once with a 12-path (instances) block (strided refs) -> KiCad expands to 12 channels.
    Self-contained (MCX inside, only +VDC/-VDC/GND global) so no hierarchical pins, nets
    auto-scope to /chNN/<net>.
    * twelve-channel.kicad_sch = 12 (sheet) instances + ONE common power section: power IN
    (J_PWR) + board-to-board DAISY out (J_DAISY) on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
    [channel.kicad_sch, multi-channel-cremat-amplifier.kicad_sch, tile.kicad_pcb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]
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2026-07-08 12ch BOM + verified protection MPNs
    Regenerated models-bom/twelve-channel-bom.csv (gen_bom.py: groups the 464 netlist parts by
    MPN/value/DNP, enriches from the single-channel BOM) = 23 line items, 344 FIT + 120 DNP.
    Verified the up-rated common-power parts (SOURCING-VERIFICATION-2026-07-08) - all 3 provisional
    picks rejected + replaced with in-stock parts (footprints unchanged, DRC still 0/0/0):
    PTC MF-MSMF110-2 (obsolete + 6V) -> Littelfuse 1812L110/24DR (1.1A/24V, 1812)
    Schk SS24 (SMB not SMA + obsolete) -> onsemi SSA24 (2A/40V, SMA)
    bulk UWT1V471MNL1GS (fictional) -> Panasonic EEE-FN1V471UP (470uF/35V, 10x10.5)
    Sizing confirmed vs the 12ch current budget (per boar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
    [twelve-channel-bom.csv, twelve-channel.kicad_sch]
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2026-07-08 Fix 12ch: duplicate #FLG refs (Update-from-Sch annotate error) + MCX model orientation
    Two user-reported bugs:
    1. Update PCB from Schematic errored on 'duplicate items FLG1/2/3'. Root cause: the ROOT sheet's
    3 rail power-flags got #FLG1/2/3, colliding with the CHILD sheet's per-channel flags (ch1's
    first flag is also #FLG1, ch2=#FLG2...). ERC/netlist missed it (power flags aren't netlist
    components) but KiCad's annotator caught it. gen_sch now offsets the root #FLG above the child
    range AND gives the root power symbols concrete #PWR refs (no '?') -> fully annotated, so
    Update-from-Schematic runs with no annotate prompt. Verified: 895 instance refs, 0 duplicates.
    2. MCX edge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
    [twelve-channel.kicad_sch]
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2026-07-11 single-channel: edge-mount MCX (user's Linx CONMCX013-T footprint) + connector orientation fixes
    - Swap MCX to the user-downloaded cremat:MCX_CONMCX013-T (shield tabs G1/G2 -> pad 2 so
    GND connects via Conn_Coaxial pin 2; trimmed the connector-tiling edge-extension
    Edge.Cuts segments). Update gen_sch FP_MCX + gen_pcb .kicad_dru condition.
    - MCX 3D model rotate (xyz 270 0 0): coax mating face now points OFF the board edge
    (raw STEP had it vertical/up). 3D-cosmetic patch to the routed board, no reroute.
    - Fix the MCX edge-notch generator: place jacks by footprint origin (rot 90/270), outline
    cuts the notch read back from each placed MCX, demote footprint Edge.Cuts -> Dwgs.User,
    keep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
    [channel.kicad_pcb, channel.kicad_sch]
2026-07-11 twelve-channel: preserve WIP schematic rebuild + record propagation plan
    - Commit the previously-uncommitted 2026-07-08 12ch schematic rebuild
    (channel.kicad_sch, twelve-channel.kicad_sch, .kicad_pro) so it survives the
    machine switch.
    - SESSION_LOG: step-by-step recipe to bring the (stale) 12ch board up to the
    single channel's connector fixes -- swap to Linx cremat:MCX_CONMCX013-T, MCX 3D
    rotate 270, edge-notch outline for all 48 MCX, J5 rot 180 -- plus pointers to the
    single-channel SESSION_LOG recipe, the KIPRJMOD render gotcha, and the FreeRouting
    (Java 25 + dead-proxy) reinstall needed on the new machine.
    [channel.kicad_sch, twelve-channel.kicad_sch]
2026-07-11 12ch: propagate single-channel connector fixes (Linx MCX-T + notch outline + J rot 180)
    Re-tiled the 12-ch board against the updated single channel (session 8). Swapped in the user's
    Linx cremat:MCX_CONMCX013-T footprint (48 instances, model rot 270 = coax off-edge); gen_pcb now
    cuts 48 edge notches (24/edge) into the outline by reading each tiled MCX's Dwgs.User cutout
    (instead of promoting cutouts to Edge.Cuts), waives edge_clearance for CONMCX013-T in .kicad_dru,
    and rotates J_PWR/J_DAISY to 180 (funnels face out, like J5). Added MPN/Mfr/DistPN fields to the
    tiled channel footprints (the regenerated single channel drops them). Deleted the old
    _EdgeMount footprint + generated STEP + obsole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
    [channel.kicad_sch, twelve-channel.kicad_sch]
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2026-07-11 12ch: SPICE AC/linearity/noise extension + purchase-ready BOM (DigiKey/Cremat/case links)
    SPICE (final-board/twelve-channel/sim):
    - Re-ran the 3-criterion system pipeline on the current (widened) design; it
    reproduces bit-identically (widening is mechanical, netlist unchanged).
    - New decks + analysis (scripts/analyze_ac_lin.py, complex-raw AC reader):
    * chain_ac -> band-pass 1.59 kHz .. 130 kHz (peak 336 kOhm); upper corner
    confirms the 1 us shaping, lower = CSP decay + CR-210 restore.
    * chain_linearity-> 133 mV/pC, linear ~1% to ~30 pC, OUT_50 hard-clip 5.13 V set
    by the THS3491 buffer railing at +10.25 V (shaper linear to 60 pC).
    *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
    [twelve-channel-bom.csv, twelve-channel-purchasing.csv]
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2026-07-11 12ch order-ready v2: socketed Cremat modules, HV-DRC fix, 1U slot-through, JLC+DigiKey ordering package
    Four workstreams, all gated (ERC 0 / netlist membership identical / DRC 0 errors,
    0 unconnected, 0 parity with hv_bias verified live / renders checked):
    SIP-8 sockets (never solder the modules):
    - All 36 module sites -> stock PinSocket_1x08 footprint (pad+courtyard identical to the
    old header placeholder). Part: Samtec SS-108-TT-2 (DK 612-SS-108-TT-2-ND) - Cremat's
    own eval-board socket; accepts the modules' 0.51x0.25mm flat pins (live-verified).
    Alt: Harwin D01-9970842. NOT Mill-Max/Preci-Dip 801 (0.7-0.9mm pins).
    hv_bias 0.6mm DRC rule was silently disabled - found and fixed at t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
    [bom-twelve-channel-jlc.csv, channel.kicad_pcb, channel.kicad_sch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]
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2026-07-20 12ch: fix KiCad opening the child sheet + regenerate twelve-channel.pdf as the schematic
    Engineer review hit two issues:
    1. Opening the project opened `channel` (child), not `twelve-channel` (root). gen_sch.py's
    sheet_file() appended (sheet_instances (path "/" (page "1"))) to BOTH files, so the child
    channel.kicad_sch declared itself a standalone root and KiCad opened it. The known-good
    reference/cremat-x6-board child has no sheet_instances block. Fix: sheet_file(is_root=...) —
    only the root emits (sheet_instances (path "/")). Regenerated: child 0 / root 1
    sheet_instances; ERC 0; netlist membership identical (271 nets); board parity still 0
    (root/project/netlist/board fi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
    [channel.kicad_sch]
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2026-07-22 12ch: fix KiCad GUI opening the channel child sheet (top_level_sheets pointed at the child)
    Real root cause (session 16's sheet_instances guess was wrong — it reproduced on the fixed
    files): twelve-channel.kicad_pro's schematic.top_level_sheets listed channel.kicad_sch as the
    project's top-level sheet. gen_sch.build_pro() copies the single-channel channel.kicad_pro
    (whose root IS channel) as its base and never re-pointed top_level_sheets at this project's
    root. kicad-cli ignores that key (filename-based root -> opened twelve-channel, so every
    headless ERC/export/render passed), but the KiCad GUI honors it and opened the child -> the
    exact kicad-cli-vs-GUI discrepancy.
    Fix: build_pro() now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
    [gen_sch.py]
2026-07-22 12ch: clean up the root common-power section (text/GND/wire cosmetics)
    Engineer review flagged three issues in the twelve-channel root power section:
    overlapping net/ref/value labels (rails 12.7mm apart, long "PTC 1.1A 24V" value
    crossing both columns); GND pins buried in the adjacent part; and power symbols
    placed directly on component pins (no wire stub) so a GUI move detached them.
    Re-laid the block as two spacious horizontal rails (+VDC top / -VDC below):
    node labels left, ref/value centred under each part, rail power-symbols and
    PWR_FLAGs on their own up-stubs pointing away, an isolated GND+flag pair for ERC,
    and a shared power_terminal() helper for J_PWR/J_DAISY (GND runs out past the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
    [channel.kicad_sch, twelve-channel.kicad_sch]
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2026-07-22 12ch: fix broken footprint<->symbol UUID paths (GUI parity 199+ / duplicate-on-update)
    The engineer's GUI DRC showed Schematic Parity 199+ and, decisively, "Update PCB
    from Schematic" DUPLICATED every component. That symptom means the footprint<->symbol
    link is broken: KiCad matches footprints to symbols by UUID sheet-path, not by
    reference. (An earlier ref-based parity check read "0 mismatches" because the NETS
    were correct -- only the UUID linkage was broken.)
    Root cause in gen_pcb.py: parse_netlist grabbed only the 36-char component tstamp and
    set each footprint path to /<symbol_uuid>, dropping the per-channel sheet prefix. The
    child sheet is instantiated 12x sharing ONE symbol uuid per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
    [channel.kicad_sch, twelve-channel.kicad_sch]
2026-07-23 Fix schematic connectivity: netclasses were missing their SCHEMATIC fields
    Root cause of the GUI showing wire T-taps as unconnected: the four netclasses in
    .kicad_pro were PCB-only. Each had clearance/track_width/via_diameter/via_drill but
    none of wire_width, bus_width, line_style, diff_pair_gap, diff_pair_width,
    microvia_diameter, microvia_drill. A netclass with no wire_width breaks eeschema's
    connectivity for every net in that class, so wires stop joining at T-taps.
    Introduced in session 15 when the hv_bias class was hand-written for the 0.6mm bias
    clearance -- the PCB half was written, the schematic half was not.
    It hid because netclasses only exist when the project is loaded: opening a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
    [channel.kicad_sch, channel_ch01.kicad_sch, channel_ch02.kicad_sch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]
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2026-07-27 Cleanup: remove inert leftover channel.kicad_sch; correct gen_sch docstring
    The singular final-board/twelve-channel/design/channel.kicad_sch was a stale
    leftover from before the session-21 "12 separate child files" refactor. It is
    NOT written by gen_sch.py (which emits channel_ch01..12 + twelve-channel.kicad_sch),
    NOT in the root schematic's sheet hierarchy, and NOT referenced by the .kicad_pro
    (the one apparent match was a substring of "twelve-channel.kicad_sch").
    Proven inert before removal: with the file parked, ERC on twelve-channel.kicad_sch
    exits 0 and the exported netlist is byte-identical (1706 refs) to the netlist with
    it present. Full acceptance gate still passes post-removal: ERC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
    [channel.kicad_sch]
2026-07-27 Schematic: revert to a single daughter file (channel.kicad_sch x12)
    Per user request, go back to ONE reused channel sheet instead of 12 separate
    files (channel_ch01..12), for maintainability -- the standard KiCad repeated-
    block pattern where you edit the sheet once.
    This is safe because session 21 established the real cause of the earlier
    wire-T-tap dropout was a netclass missing its SCHEMATIC fields, NOT the sheet
    reuse. That fix is in place (build_pro fills the 7 fields, verified), so the
    single-daughter design is electrically valid -- as the independent Moore-Lab
    board confirmed by running exactly this case.
    gen_sch.py: implemented the previously-missing instances_multi() + a
    sym_insta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
    [channel.kicad_sch, channel_ch01.kicad_sch, channel_ch02.kicad_sch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]
2026-07-30 Order finalize: MCX/pot/terminal to JLC assembly, CPL placement fixes, 2U box, 5-board build
    Assembly sourcing + placement corrections for the JLC order, plus the enclosure
    switch and 5-board build plan.
    - MCX: BAT WIRELESS BWMCX-KEF (LCSC C5250059) on the existing Linx CONMCX013 land;
    JLC *Standard* tier (the part is Standard-only). Added to JLC BOM + CPL (J1-J48).
    - Trimpots (RV1-RV12, JIERR 3296W-1-204 / C48997932) and screw terminals
    (J49-J50, Cixi Kefa KF128-5.0-3P / C474951) moved from DigiKey hand-solder to
    JLC THT wave-solder; added to BOM + CPL. BOM now 15 lines, CPL 308 placements.
    - D1/D2 diode polarity: +180 deg CPL rotation so the cathode band lands on pad 1,
    plus a sil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
    [bom-twelve-channel-jlc.csv, digikey-hand-bom.csv, twelve-channel.kicad_pcb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]
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
